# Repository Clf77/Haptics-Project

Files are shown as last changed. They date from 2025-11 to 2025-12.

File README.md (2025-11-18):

# Raspberry Pi Pico CQR37D Motor Controller

This project provides Python code to control a CQRobot CQR37D DC geared motor with quadrature encoder using a Raspberry Pi Pico microcontroller. It supports both position and velocity control through a command-line interface.

## Hardware Setup

### Required Components
- Raspberry Pi Pico
- CQRobot CQR37D DC Geared Motor with Encoder
- DROK XY-160D Motor Controller (or similar DC motor controller)
- Power supply (appropriate voltage for your motor - typically 6V, 12V, or 24V)

### Pin Connections

| Component | Pico Pin | GPIO | Wire Color (Encoder) |
|---|---|---|---|
| Encoder A | 9 | GP8 | White |
| Encoder B | 10 | GP9 | Yellow |
| Motor ENA | 1 | GP0 | Controller PWM Input |
| Motor IN1 | 2 | GP1 | Controller Direction |

### Motor Controller Setup (DROK XY-160D)
- **ENA**: Connected to Pico GP0 (pin 1) - PWM speed control
- **IN1**: Connected to Pico GP1 (pin 2) - Direction control
- **Power**: Connect appropriate DC voltage to motor controller power terminals
- **Motor**: Connect motor leads to controller output

## Software Setup

### Requirements
- MicroPython installed on Raspberry Pi Pico
- Thonny IDE (recommended) or another MicroPython editor

### Installation
1. Copy `motor_control.py` to your Raspberry Pi Pico
2. Open the file in Thonny or your preferred editor
3. Run the script

## Configuration

### Motor Parameters
Edit these values in the `MotorController.__init__()` method:

```python
self.CPR = 64  # Counts per revolution (fixed for CQR37D)
self.gear_ratio = 30.0  # Your motor's gear ratio (check your motor specs)
self.max_rpm = 150.0  # Maximum RPM for your motor/voltage combination
```

### PID Tuning (for Position Control)
Default PID values are provided, but you may need to tune them:

```python
self.kp = 2.0   # Proportional gain
self.ki = 0.1   # Integral gain
self.kd = 0.05  # Derivative gain
```

## Usage

### Command Line Interface

Run the script and use these commands:

#### Position Control
```
pos <degrees>     - Move to absolute position in degrees
Example: pos 180    (move to 180 degrees)
```

#### Velocity Control
```
vel <rpm>         - Set constant velocity in RPM
Example: vel 50     (spin at 50 RPM clockwise)
Example: vel -30    (spin at 30 RPM counter-clockwise)
```

#### Other Commands
```
stop              - Stop the motor
zero              - Zero the position counter (set current position to 0)
status            - Show current position, velocity, and control mode
pid <kp> <ki> <kd> - Set PID gains for position control
help              - Show all available commands
quit              - Exit the program
```

### Example Usage Session
```
Motor controller initialized
Encoder CPR: 64, Gear ratio: 30.0
Counts per output revolution: 1920.0

Type 'help' for available commands
Current mode: velocity control

vel 30
Velocity control: target = 30 RPM

status
Position: 45.67 degrees
Velocity: 29.85 RPM
Control mode: velocity
Target velocity: 30.00 RPM

pos 90
Position control: target = 90 degrees

status
Position: 89.94 degrees
Velocity: 0.12 RPM
Control mode: position
Target position: 90.00 degrees

stop
Motor stopped

quit
Exiting...
```

## Technical Details

### Encoder
- **Type**: Quadrature encoder with 64 counts per revolution (motor shaft)
- **Resolution**: After gearing, depends on your gear ratio
- **Interface**: Uses hardware interrupts for real-time position tracking

### Motor Control
- **Speed Control**: PWM on ENA pin (1kHz frequency)
- **Direction Control**: Digital output on IN1 pin
- **Deadband Compensation**: Minimum PWM value to overcome motor stall

### Control Modes

#### Velocity Control
- Direct RPM control
- Immediate response to velocity commands
- Good for continuous rotation applications

#### Position Control
- PID-based position control
- Maintains target angular position
- Includes integral windup protection

### Performance Considerations
- **Control Loop**: Runs at 100Hz (10ms intervals)
- **Position Accuracy**: Depends on encoder resolution and PID tuning
- **Maximum Speed**: Limited by motor capabilities and PWM frequency
- **Interrupt Latency**: MicroPython interrupt response time may affect high-speed performance

## Troubleshooting

### Common Issues

1. **Motor not moving**
   - Check power supply voltage and connections
   - Verify motor controller wiring
   - Ensure minimum PWM threshold is set correctly

2. **Inaccurate position**
   - Calibrate encoder count per revolution
   - Tune PID parameters
   - Check for mechanical backlash

3. **Velocity oscillations**
   - Reduce P gain
   - Increase D gain
   - Check encoder signal quality

4. **No encoder feedback**
   - Verify encoder pin connections
   - Check encoder power supply (3.3V-24V)
   - Ensure encoder wires are properly seated

### Calibration

1. **Encoder CPR**: Use the known value (64 for CQR37D)
2. **Gear Ratio**: Measure or check motor specifications
3. **Maximum RPM**: Test under load with your power supply
4. **PID Gains**: Start with low values and increase gradually

## Safety Notes

- **Power Supply**: Use appropriate voltage for your motor
- **Current Limiting**: Ensure your power supply can handle motor stall current
- **Mechanical Limits**: Add physical stops if needed to prevent over-rotation
- **Heat Dissipation**: Monitor motor and controller temperatures during operation

## License

This code is provided as-is for educational and experimental purposes.

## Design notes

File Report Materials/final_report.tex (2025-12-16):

\documentclass[conference]{IEEEtran}
\IEEEoverridecommandlockouts

\usepackage{cite}
\usepackage{amsmath,amssymb,amsfonts}
\usepackage{algorithmic}
\usepackage{graphicx}
\usepackage{textcomp}
\usepackage{xcolor}
\usepackage{listings}
\usepackage{tikz}
\usepackage{url}
\usepackage{float}
\usetikzlibrary{shapes,arrows,positioning}

% Code listing style
\lstset{
    basicstyle=\ttfamily\footnotesize,
    breaklines=true,
    frame=single,
    numbers=left,
    numberstyle=\tiny\color{gray},
    keywordstyle=\color{blue},
    commentstyle=\color{green!60!black},
    stringstyle=\color{red},
    showstringspaces=false
}

\def\BibTeX{{\rm B\kern-.05em{\sc i\kern-.025em b}\kern-.08em
    T\kern-.1667em\lower.7ex\hbox{E}\kern-.125emX}}

\begin{document}

\title{Haptic Lathe Simulator\\
{\large MAE 6800: Design and Control of Haptic Systems, Fall 2025}}

\author{\IEEEauthorblockN{Caleb Farrelly, Daria Kot, and Richard Zheng}
\IEEEauthorblockA{\textit{Sibley School of Mechanical and Aerospace Engineering} \\
\textit{Cornell University}\\
Ithaca, NY, USA}
}

\maketitle

\begin{abstract}
We present the design and implementation of a haptic lathe training device that simulates the tactile experience of operating a manual lathe. The system integrates a directly-driven handwheel with a virtual lathe environment, providing force feedback based on tool-material interaction, spindle speed, and cutting depth. Using a geared DC motor with a quadrature encoder as the haptic interface and a Processing-based graphical user interface, the device enables trainees to develop muscle memory for common machining operations in a low-risk setting. The haptic rendering algorithm employs a damping-based virtual wall model derived from the Hapkit framework, with material-specific force profiles for Delrin, Aluminum 6061, Stainless Steel 316, and Inconel. This paper details the system architecture, hardware implementation, control algorithms, and force rendering equations.
\end{abstract}

\begin{IEEEkeywords}
haptics, lathe simulator, force feedback, virtual machining, training systems
\end{IEEEkeywords}

\section{Introduction}

\subsection{Motivation}

Traditional lathe training relies on access to full-scale machines and close expert supervision, and it carries inherent risks including injury, tool damage, and material waste. Novice machinists must develop the tactile ``feel'' of cutting---recognizing overly aggressive feeds, dull tools, chatter onset, and material-dependent behavior at the tool--workpiece interface. Developing this intuition typically requires extensive hands-on practice.

Haptic technology offers a safer and more accessible alternative: virtual training environments that provide force feedback without the cost or hazard of physical machining. We present a two-DOF haptic lathe simulator that reproduces the hand-feel of manual lathe operation using a directly driven handwheel that can be toggled between the X cross-slide and Z carriage axes. A virtual lathe environment renders stock geometry, tool position, target drawings, and tolerances, and live X/Z readouts. The system computes and reflects cutting forces and torques as functions of spindle speed, feed, and depth of cut, enabling trainees to practice core operations such as facing and turning to diameter while building correct muscle memory in a low-risk setting.

\subsection{Educational Objectives}

The Haptic Lathe Simulator is designed to achieve the following educational objectives:

\begin{enumerate}
    \item \textbf{Muscle Memory Development}: Users develop proper hand coordination for feed control by experiencing realistic resistance during cutting operations.
    \item \textbf{Material Differentiation}: Different materials (Delrin, Aluminum, Stainless Steel, Inconel) present distinct force profiles, teaching users to recognize and adapt to material properties.
    \item \textbf{Safety Awareness}: The system simulates crash conditions when the tool contacts the workpiece with the spindle stopped and provides increased haptic resistance for overly aggressive cutting attempts, reinforcing safe operating procedures and proper feed control.
    \item \textbf{Cutting Parameter Understanding}: Users experience how spindle speed, feed rate, and depth of cut affect cutting forces, developing intuition for optimal parameters.
\end{enumerate}

\subsection{Prior Work in Haptic Machining Simulation}

A complementary user study by \cite{ieeeT4E2018} examined the perceived importance of haptic cues at the lathe handwheel across beginner, intermediate, and expert operators. Using a questionnaire-based methodology and chi-square analysis, the study found a statistically significant relationship between operator experience and perceived force intensity: beginners reported strong reliance on haptic feedback, whereas expert users perceived weaker force cues. These findings suggest that physically meaningful handwheel feedback plays a critical role during early motor-skill acquisition and motivate the inclusion of haptics in lathe training simulators.

Significant prior work has explored force-feedback interfaces for virtual machining, with an emphasis on modeling tool--workpiece interaction and material removal in real time. Early systems such as the Haptic Virtual Turning Operation System (HVTOS) employed efficient workpiece deformation algorithms to generate continuous force feedback as a function of cutting depth and material properties \cite{he2006haptic}. However, force feedback in this work was rendered using a commercial PHANToM haptic device, which, while capable of high-fidelity kinesthetic output, is expensive and does not reflect the mechanical interaction of a manual lathe, where feedback is transmitted through a rotating handwheel.

Subsequent research expanded virtual machining toward immersive visual and mixed-reality training platforms, emphasizing three-dimensional visualization, task sequencing, and safety instruction rather than physically rendered cutting forces \cite{ieee8590115, sciencedirect2016, springer2023vr}. In many of these systems, user interaction is limited to kinematic input---such as rotating a handwheel or manipulating a virtual tool---without explicit force or torque feedback. Educational implementations such as the \textit{Turnin' and Burnin'} lathe similarly focus on visual understanding of machining operations and geometry while omitting continuous, physically meaningful haptic feedback through the handwheel \cite{turninburnin}.

In contrast, the haptic lathe simulator presented in this work emphasizes the continuous, parameter-dependent hand feel of manual lathe operation. By using a directly driven handwheel and a damping-based force rendering model explicitly tied to feed rate, spindle speed, depth of cut, and material properties, our system prioritizes kinesthetic realism and muscle-memory development.

\section{System Overview}
The haptic lathe simulator consists of three primary subsystems:

\begin{enumerate}
    \item \textbf{Haptic Interface}: A CQR37D geared DC motor with integral quadrature encoder, directly coupled to a handwheel that serves as both position input and force feedback output.
    \item \textbf{Virtual Environment}: A Processing-based graphical user interface that renders the lathe workpiece, tool position, and material removal in real-time.
    \item \textbf{Control Bridge}: A Python-based communication layer that manages bidirectional data flow between the GUI and microcontroller while computing haptic forces.
\end{enumerate}

\begin{figure}[H]
    \centering
    
    \caption{Haptic Lathe Simulator Setup}
    \label{fig:placeholder}
\end{figure}
\begin{figure}[H]
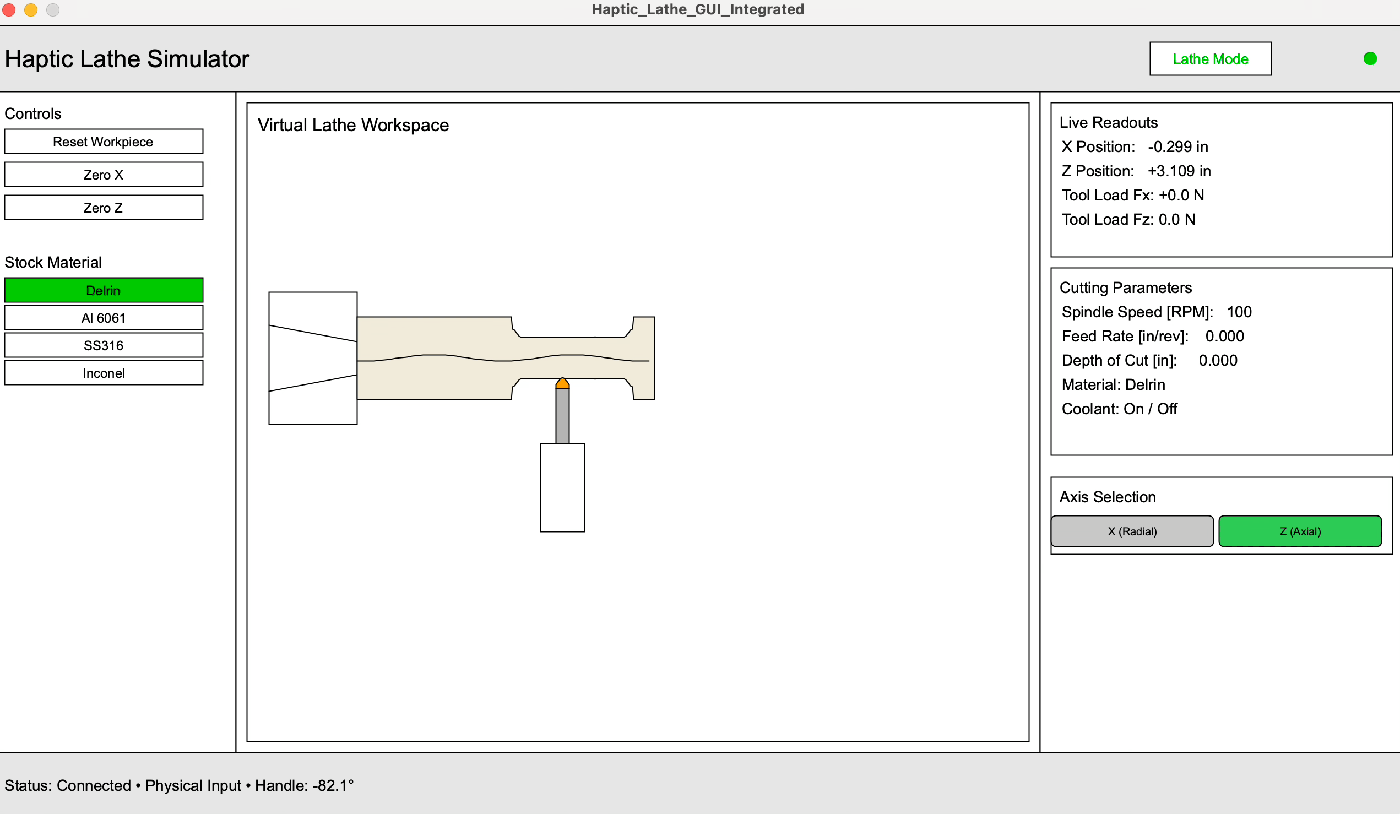
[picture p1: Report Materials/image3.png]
\centerline{}
\caption{Virtual Environment showing Delrin being cut.}
\label{fig:gui}
\end{figure}

\subsection{Project Scope}

The presented work demonstrates the principles of machining with real-time force feedback to replicate the two primary control inputs of a conventional manual lathe: the X cross-slide and the Z carriage. The resultant device is a two-DOF haptic trainer featuring one directly-driven handwheel to ensure high-fidelity transmission of simulated forces, with the operator being able to rapidly switch between the two axes. By concentrating the design on a low-inertia, directly-coupled system, the device minimizes parasitic friction and backlash, which are critical design considerations in high-precision mechanical assemblies. The system computes and reflects realistic cutting forces and torques based on operational variables, allowing trainees to practice basic machining operations (e.g., facing, turning to a specified diameter) in a safe virtual environment.

\subsection{Virtual Wall Rendering}

Virtual walls are fundamental haptic primitives that create the sensation of solid surfaces. When a user penetrates a virtual wall, the haptic device generates a restoring force proportional to penetration depth:
\begin{equation}
    F = k \cdot x
    \label{eq:spring_wall}
\end{equation}
where $k$ is the wall stiffness (N/m) and $x$ is the penetration depth (m). Pure spring walls can feel ``buzzy'' at high stiffness values, motivating the addition of damping:
\begin{equation}
    F = k \cdot x + b \cdot \dot{x}
    \label{eq:spring_damper}
\end{equation}
where $b$ is the damping coefficient (Ns/m) and $\dot{x}$ is the penetration velocity (m/s).

\subsection{Cutting Force Modeling}

In actual machining, the feed force experienced by the lathe's feed mechanism is given by:
\begin{equation}
    F_f = K_c \cdot f \cdot a_p
    \label{eq:cutting_force}
\end{equation}
where $K_c$ is the specific cutting force of the workpiece material (N/mm$^2$), $f$ is the feed per revolution (mm/rev), and $a_p$ is the depth of cut (mm). This relationship guides our haptic rendering strategy: cutting forces should increase with feed rate (velocity) and depth of cut (penetration).

\section{System Architecture}

\subsection{Architecture Overview}

The system employs a three-tier architecture with clear separation of concerns. Fig.~\ref{fig:architecture} shows the data flow between components.

% Preamble:
% \usetikzlibrary{positioning}

\begin{figure}[htbp]
\centering
\resizebox{\linewidth}{!}{%
\begin{tikzpicture}[
  node distance=1.1cm and 1.1cm,
  block/.style={
    rectangle, draw, fill=blue!20,
    text width=2.2cm, align=center,
    minimum height=1.05cm, font=\footnotesize
  },
  arrow/.style={->, thick},
  lab/.style={font=\scriptsize, fill=white, inner sep=1pt}
]

\node[block] (gui)    {Processing GUI\\(Visual)};
\node[block, right=of gui]    (bridge) {Python Bridge\\(Comm.)};
\node[block, right=of bridge] (pico)   {RPi Pico\\(Control)};
\node[block, below=of pico]   (motor)  {CQR37D\\Motor};

\draw[arrow] (gui.east)    -- node[lab, above] {TCP/IP} (bridge.west);
\draw[arrow] (bridge.east) -- node[lab, above] {Serial} (pico.west);
\draw[arrow] (pico.south)  -- (motor.north);

% Feedback path: orthogonal into faces, label offset and masked
\draw[arrow] (motor.west) -|
  node[lab, pos=0.18, above, yshift=2pt] {Position}
  (bridge.south);

\end{tikzpicture}%
}
\caption{System architecture showing data flow between components.}
\label{fig:architecture}
\end{figure}

\subsection{Communication Protocol}

The Processing GUI sends JSON-formatted commands to the Python bridge via TCP/IP on port 5005. High-speed force commands are sent at 100Hz using the format: \texttt{FORCE:<Fx>,<Fz>,<Freq>,<Yield>}.

The bridge sends text commands to the Pico microcontroller via serial at 921600 baud, including commands such as \texttt{spring\_wall}, \texttt{status}, \texttt{stop}, and \texttt{zero}.

\subsection{Update Rates}

Table~\ref{tab:timing} shows the system update rates to ensure responsive haptic feedback.

\begin{table}[htbp]
\caption{System timing parameters.}
\begin{center}
\begin{tabular}{|l|c|l|}
\hline
\textbf{Component} & \textbf{Rate} & \textbf{Purpose} \\
\hline
Pico control loop & 100 Hz & Force rendering, motor control \\
Bridge main loop & 500 Hz & Communication management \\
GUI rendering & 60 Hz & Visualization \\
Position polling & 100 Hz & Encoder/state feedback \\
Safety checks & 20 Hz & Timeouts, limits \\
\hline
\end{tabular}
\label{tab:timing}
\end{center}
\end{table}

\section{Hardware Implementation}

\subsection{Component Selection}

The haptic interface requires a motor capable of sufficient torque for realistic cutting force simulation, low friction for transparent backdrivability, and integrated encoder for position sensing.

We selected the \textbf{CQRobot CQR37D} geared DC motor. Table~\ref{tab:motor} shows its specifications. The 30:1 gear ratio provides mechanical advantage, amplifying motor torque while reducing output speed---appropriate for the slow, deliberate movements of lathe handwheel operation.

\begin{table}[htbp]
\caption{CQR37D Motor Specifications}
\begin{center}
\begin{tabular}{|l|l|}
\hline
\textbf{Parameter} & \textbf{Value} \\
\hline
Gear Ratio & 30:1 \\
Encoder CPR & 64 counts/rev (motor shaft) \\
Effective Resolution & 1920 counts/output rev \\
Rated Voltage & 12V DC \\
No-Load Speed & 150 RPM \\
Stall Torque & 3.1 Nm \\
\hline
\end{tabular}
\label{tab:motor}
\end{center}
\end{table}

The \textbf{Raspberry Pi Pico} provides dual-core ARM Cortex-M0+ at 133 MHz, hardware PWM for motor control, GPIO interrupts for encoder counting, and MicroPython support for rapid development.

\subsection{Wiring Configuration}

Table~\ref{tab:wiring} shows the hardware pin connections.

\begin{table}[htbp]
\caption{Hardware Pin Connections}
\begin{center}
\begin{tabular}{|l|l|l|l|}
\hline
\textbf{Component} & \textbf{Pico Pin} & \textbf{GPIO} & \textbf{Color} \\
\hline
Encoder A & Pin 9 & GP6 & White \\
Encoder B & Pin 10 & GP7 & Yellow \\
Motor ENA & Pin 1 & GP0 & --- \\
Motor IN1 & Pin 4 & GP2 & --- \\
Motor IN2 & Pin 2 & GP1 & --- \\
\hline
\end{tabular}
\label{tab:wiring}
\end{center}
\end{table}

\subsection{Bill of Materials}

Table~\ref{tab:bom} shows the complete bill of materials.

\begin{table}[htbp]
\caption{Bill of materials (excluding 3D-printed parts).}
\begin{center}
\begin{tabular}{|l|c|r|}
\hline
\textbf{Item} & \textbf{Qty} & \textbf{Cost} \\
\hline
Raspberry Pi Pico & 1 & \$4.00 \\
CQR37D geared DC motor (30:1) & 1 & \$34.00 \\
Motor driver (H-bridge) & 1 & \$15.70 \\
Shaft coupler & 1 & \$4.50 \\
\hline
\textbf{Total} & & \textbf{\$58.20} \\
\hline
\end{tabular}
\label{tab:bom}
\end{center}
\end{table}

\subsection{Mechanical Design}

\begin{figure}[htbp]
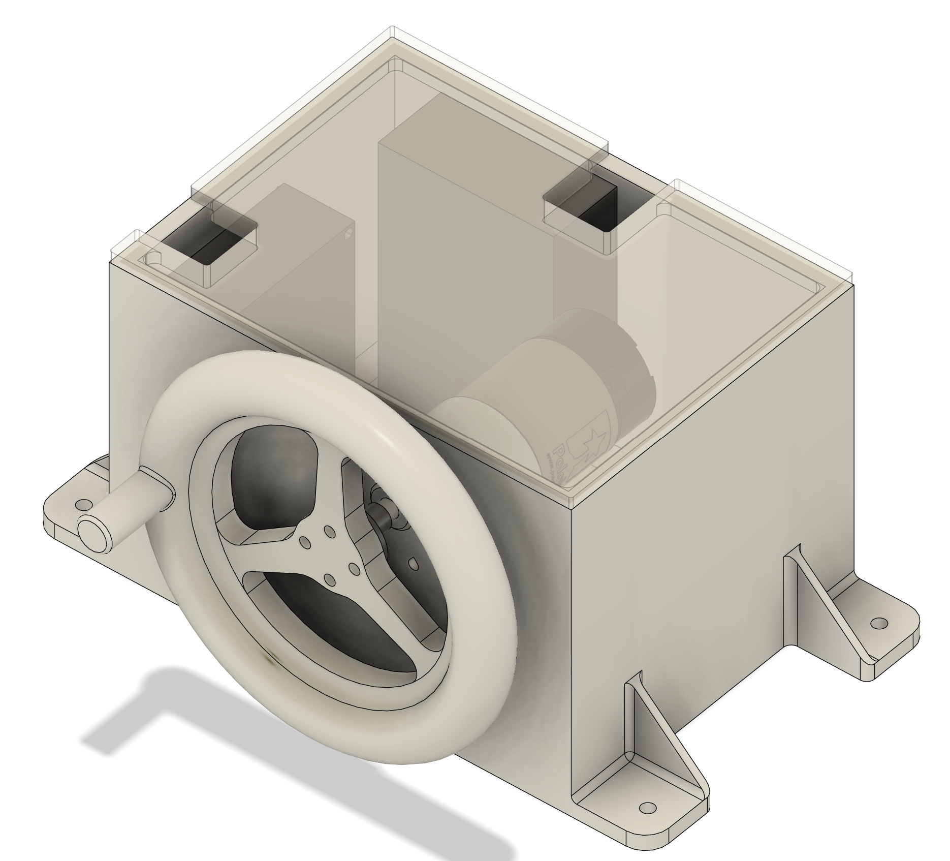
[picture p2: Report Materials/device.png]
\centerline{}
\caption{CAD of the Lathe Simulator with transparent lid.}
\label{fig:device}
\end{figure}

The mechanical assembly (Fig.~\ref{fig:device}) includes: 3D-printed housing with integrated mounting for motor and boards, 3D-printed handwheel (90mm OD) with ergonomic grip, shaft coupler connecting motor output to handwheel, and flanged base for suction cup attachment that can be clamped to the table.

\section{Software Implementation}

\subsection{Motor Control (MicroPython)}

The motor controller runs on the Raspberry Pi Pico, implementing real-time position tracking and force rendering.

\subsubsection{Quadrature Encoder Decoding}

The encoder uses hardware interrupts to track motor position. Position in degrees is computed as:
\begin{equation}
    \theta = \frac{\text{encoder\_count}}{\text{CPR} \times \text{gear\_ratio}} \times 360^\circ
    \label{eq:position}
\end{equation}

For our system: $\theta = \frac{\text{count}}{64 \times 30} \times 360^\circ = \frac{\text{count}}{1920} \times 360^\circ$.

\subsubsection{Velocity Calculation}

Angular velocity is computed by differentiating encoder counts:
\begin{equation}
    \omega = \frac{\Delta\text{count}}{\text{CPR} \times \text{gear\_ratio}} \times \frac{60}{\Delta t} \quad \text{[RPM]}
    \label{eq:velocity}
\end{equation}

An IIR low-pass filter smooths the velocity estimate:
\begin{equation}
    \dot{x}_{\text{filt}} = 0.9 \cdot \dot{x} + 0.1 \cdot \dot{x}_{\text{prev}}
    \label{eq:velocity_filter}
\end{equation}

\subsection{Virtual Wall Force Rendering}

The haptic feedback algorithm implements a damping-based cutting force model inspired by the Hapkit framework.
\subsection{Control Loop and Force Pipeline}

Fig.~\ref{fig:forcepipeline} summarizes the haptic rendering pipeline executed each control cycle. The Pico runs a fixed-rate loop at 100~Hz. Encoder counts are converted to angle $\theta$, differentiated to estimate angular velocity $\omega$, filtered, and then mapped to a handle-space linear velocity $\dot{x}_{\text{filt}} = \omega_{\text{filt}} r_h$. Penetration depth $x_{\text{pen}}$ is computed relative to the current virtual wall location. The damping-based cutting force in (8) is then converted to motor torque (9) and mapped to PWM duty (10). Finally, direction and safety logic clamp output based on penetration limits and heartbeat timeout.

\begin{figure}[htbp]
\centering
\begin{tikzpicture}[
  node distance=0.9cm,
  block/.style={rectangle, draw, fill=blue!15, text width=7.0cm, minimum height=0.75cm, align=center, font=\footnotesize},
  arrow/.style={->, thick}
]
\node[block] (enc) {Encoder counts $\rightarrow$ angle $\theta$ (Eq.~\ref{eq:position})};
\node[block, below=of enc] (vel) {Differentiate $\theta$ $\rightarrow$ $\omega$ (Eq.~\ref{eq:velocity}); low-pass filter (Eq.~\ref{eq:velocity_filter})};
\node[block, below=of vel] (handle) {Map to handle velocity: $\dot{x}_{\text{filt}}=\omega_{\text{filt}}\cdot \frac{2\pi}{60}\cdot r_h$};
\node[block, below=of handle] (pen) {Penetration depth $x_{\text{pen}}$ (Eq.~\ref{eq:penetration}) and engagement state};
\node[block, below=of pen] (force) {Compute force $F$ (Eq.~\ref{eq:damping_force}) with material scaling + yield threshold};
\node[block, below=of force] (pwm) {Torque + PWM mapping (Eq.~\ref{eq:motor_torque}, Eq.~\ref{eq:hapkit_duty}) + safety clamps};
\draw[arrow] (enc) -- (vel);
\draw[arrow] (vel) -- (handle);
\draw[arrow] (handle) -- (pen);
\draw[arrow] (pen) -- (force);
\draw[arrow] (force) -- (pwm);
\end{tikzpicture}
\caption{Force rendering pipeline executed each Pico control cycle.}
\label{fig:forcepipeline}
\end{figure}

\subsubsection{Parameterization Used in This Prototype}
The prototype used the following fixed parameters: handle radius $r_h = 0.05$~m; base damping $c_{\text{base}} = 2000$~Ns/m; depth scaling saturation $d_{\text{scale}} = \min(x_{\text{pen}}/0.005,\,2.0)$; maximum penetration of 200$^\circ$; and a 5~s heartbeat timeout. Material differences were implemented by scaling the effective damping via the yield force $F_{\text{wall}}$ (Table~\ref{tab:materials}) as $c_{\text{damping}} = c_{\text{base}} \cdot (F_{\text{wall}}/50)$, producing a 4:1 spread between Delrin and Inconel.

\subsubsection{Penetration Detection}

When the tool enters the workpiece, penetration depth is computed:
\begin{equation}
    x_{\text{pen}} = (\theta_{\text{current}} - \theta_{\text{wall}}) \cdot \text{dir} \cdot \frac{\pi}{180} \cdot r_h
    \label{eq:penetration}
\end{equation}
where $r_h = 0.05$ m is the effective handle radius.

\subsubsection{Damping-Based Force Calculation}

The cutting force is computed using velocity-proportional damping, scaled by penetration depth:
\begin{equation}
    F = -\dot{x}_{\text{filt}} \cdot c_{\text{damping}} \cdot (1 + d_{\text{scale}})
    \label{eq:damping_force}
\end{equation}
where $\dot{x}_{\text{filt}}$ is the filtered velocity at handle (m/s), $c_{\text{damping}} = c_{\text{base}} \times \frac{F_{\text{wall}}}{50}$ is the material-scaled damping with $c_{\text{base}} = 2000$ Ns/m, and $d_{\text{scale}} = \min\left(\frac{x_{\text{pen}}}{0.005}, 2.0\right)$ is the depth scaling factor.

\subsubsection{Torque-to-PWM Conversion}

The computed force is converted to motor torque and then to PWM duty cycle using the Hapkit non-linear mapping:
\begin{equation}
    T_p = \frac{F \cdot r_h}{\text{gear\_ratio}}
    \label{eq:motor_torque}
\end{equation}
\begin{equation}
    \text{duty} = \sqrt{\frac{|T_p|}{0.03}}
    \label{eq:hapkit_duty}
\end{equation}

This square-root relationship linearizes the perceived force output.

\subsection{Material Properties}

Different materials are simulated by varying the wall stiffness $k_{\text{wall}}$ and yield force. Table~\ref{tab:materials} shows the material haptic properties.

\begin{table}[htbp]
\caption{Material Haptic Properties}
\begin{center}
\begin{tabular}{|l|c|c|c|}
\hline
\textbf{Material} & \textbf{$k_{\text{wall}}$ (N/m)} & \textbf{Yield (N)} & \textbf{Color} \\
\hline
Delrin & 50,000 & 25 & Cream \\
Al 6061 & 100,000 & 50 & Silver \\
SS316 & 150,000 & 75 & Steel \\
Inconel & 200,000 & 100 & Bronze \\
\hline
\end{tabular}
\label{tab:materials}
\end{center}
\end{table}

The 4:1 ratio between softest (Delrin) and hardest (Inconel) materials provides clear tactile differentiation.

\subsection{Graphical User Interface}

The Processing-based GUI provides: (1) Virtual Lathe Workspace with real-time rendering of stock geometry, tool position, and material removal; (2) Live Readouts of X/Z position, tool load, and cutting parameters; (3) Control Panel for material selection, axis selection, and reset/zero functions; and (4) Connection Status with visual indicator for bridge connectivity.

\begin{figure}[H]
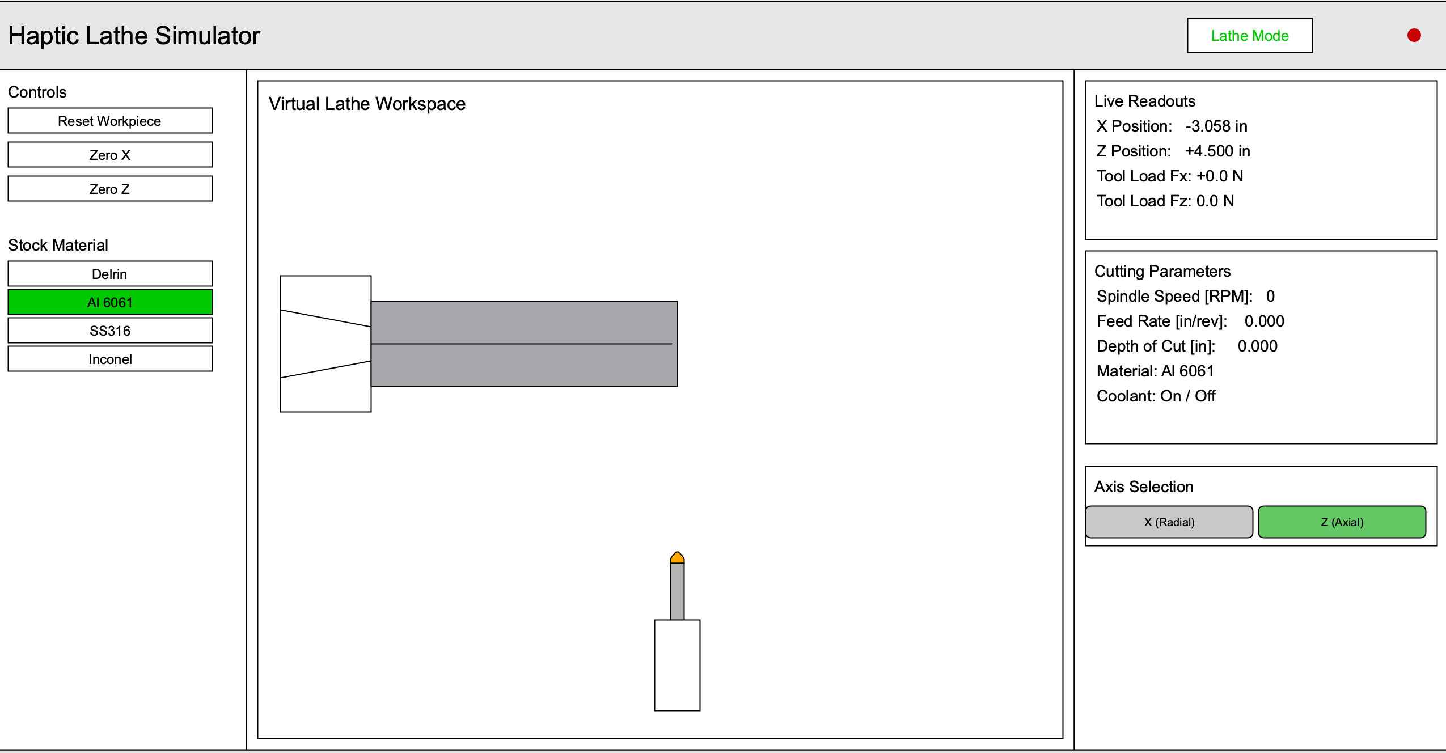
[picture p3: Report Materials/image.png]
\centerline{}
\caption{Virtual Environment showing the lathe workspace.}
\label{fig:gui}
\end{figure}

\subsubsection{Collision Detection}

The tool uses a hyperbolic profile for realistic V-tool geometry:
\begin{equation}
    y = \sqrt{(s \cdot x)^2 + R^2} - R
    \label{eq:hyperbolic_tool}
\end{equation}
where $s$ is the slope factor and $R$ is the tool tip radius. Collision is detected when the tool profile intersects the stock profile array at any Z-position.

\subsubsection{Vibration Frequency Calculation}

Cutting vibration frequency is mapped from surface feet per minute (SFM):
\begin{equation}
    \text{SFM} = \frac{\text{RPM} \times D \times \pi}{12}
    \label{eq:sfm}
\end{equation}
\begin{equation}
    f_{\text{vib}} = \text{SFM} \quad \text{[Hz]}
    \label{eq:vib_freq}
\end{equation}

This 1:1 mapping (10 SFM = 10 Hz) provides intuitive correspondence between spindle speed and haptic vibration.

\section{Results}

\subsection{Design Decisions}

Several key design decisions shaped the final system:

\begin{enumerate}
    \item \textbf{Damping-based vs. Spring-based Force Rendering}: We chose velocity-proportional damping over pure spring walls because cutting forces in actual machining are primarily determined by feed rate (velocity) rather than static position. This produces a more realistic ``cutting feel.''
    \item \textbf{Single-Axis Interface}: While a complete lathe has two axes (X and Z), we implemented a single handwheel with software axis selection. This reduces hardware complexity while maintaining training value through the axis toggle feature.
    \item \textbf{Motor as Input and Output}: Using the motor encoder as the position input (rather than a separate sensor) enables the same device to serve as both input transducer and force actuator.
\end{enumerate}

\subsection{Limitations}

\begin{enumerate}
    \item \textbf{Single Degree of Freedom}: Real lathe operation involves simultaneous X and Z control. The single-axis interface requires users to mentally switch between axes.
    \item \textbf{No Force Sensing}: The system renders forces based on virtual geometry only; actual cutting force measurement would require additional sensors.
    \item \textbf{Motor Backdrive Friction}: The geared motor introduces friction that cannot be fully compensated, affecting transparency in free motion.
\end{enumerate}

\subsection{User Study}

A formative user study was conducted during a public demonstration of the haptic lathe simulator to evaluate perceived realism, usefulness of the haptic cues, and overall learning impact. The study was exploratory (not a controlled experiment) and focused on subjective perception and qualitative feedback.

\subsubsection{Procedure}
Participants interacted freely with the simulator and were encouraged to (i) toggle between axes, (ii) try multiple materials, and (iii) vary depth of cut and feed behavior to observe changes in resistance and vibration. After the interaction, participants completed a short questionnaire with 10-point Likert items (1 = strongly disagree, 10 = strongly agree) and optional open-ended comments. Participants also answered whether they felt more confident operating a lathe afterward (Yes/No).

\subsubsection{Participants}
Ten participants completed the questionnaire ($N=10$). Seven reported prior lathe experience, two reported no prior lathe experience, and one left the question blank. This mix allowed feedback from both experienced users (realism expectations) and novices (interpretability of cues).

\subsubsection{Measures}
Participants rated the following statements: (1) The simulation was realistic; (2) The materials were differentiable; (3) Force changes communicate tool engagement; (4) I could tell when I was doing something ``wrong'' based on feel alone; (5) The visual and haptic cues were synchronized; (6) The simulator helped me understand lathe cutting dynamics. Participants also reported whether they felt more confident operating a lathe after use.

\subsubsection{Results}
Table~\ref{tab:userstudy} summarizes the Likert responses. Overall scores were high across all dimensions, with particularly strong ratings for visual--haptic synchronization and understanding of cutting dynamics. All participants reported increased confidence operating a lathe after using the simulator (10/10 ``Yes'').

\begin{table}[htbp]
\caption{User study Likert responses (1--10).}
\begin{center}
\begin{tabular}{lccc}
\hline
\textbf{Statement} & \textbf{Mean} & \textbf{SD} & \textbf{Range} \\
\hline
Simulation was realistic & 8.9 & 0.9 & 8--10 \\
Materials differentiable & 9.0 & 1.1 & 7--10 \\
Force indicates engagement & 9.0 & 1.6 & 6--10 \\
Could detect ``wrong'' by feel & 8.4 & 1.6 & 5--10 \\
Visual--haptic synchronized & 9.9 & 0.3 & 9--10 \\
Helped understand cutting dynamics & 9.8 & 0.6 & 8--10 \\
\hline
\end{tabular}
\label{tab:userstudy}
\end{center}
\end{table}

\begin{table}[htbp]
\caption{User study means by experience group (Likert 1--10).}
\begin{center}
\begin{tabular}{lcc}
\hline
\textbf{Statement} & \textbf{Experienced (n=7)} & \textbf{Novice (n=2)} \\
\hline
Simulation was realistic & 8.6 & 9.5 \\
Materials differentiable & 9.1 & 9.0 \\
Force indicates engagement & 9.1 & 10.0 \\
Could detect ``wrong'' by feel & 8.1 & 8.5 \\
Visual--haptic synchronized & 9.9 & 9.5 \\
Helped understand cutting dynamics & 9.7 & 10.0 \\
\hline
\end{tabular}
\label{tab:userstudy_groups}
\end{center}
\end{table}

\noindent
Novice users tended to rate tool engagement and learning impact slightly higher, while experienced users provided more critical realism scores, consistent with expert calibration to real machine feel. Although the novice sample is small, this split suggests the simulator is interpretable for first-time learners while remaining recognizable to users with prior lathe exposure.

\subsubsection{Qualitative Feedback}
Open-ended comments highlighted (i) perceived realism of resistance changes with depth of cut (including experienced-user agreement that it ``matched the feel''), and (ii) the usefulness of haptic cues for identifying aggressive cutting without relying on visuals. One participant noted that the suction-cup mounting reduced immersion, suggesting improved fixturing (e.g., clamps or a heavier base) for future iterations.

\subsubsection{Study Limitations}
This evaluation was conducted in an uncontrolled demo setting with a small sample size, so results should be interpreted as formative. Participants had different exposure times and explored different subsets of operations. A controlled follow-on study could standardize tasks (e.g., facing to a target diameter under fixed spindle speed), compare conditions (haptics on/off), and measure objective performance (time-to-completion, overshoot, surface error, and number of ``crash'' events).

\subsection{Discussion}

The results suggest that the simulator successfully conveys key aspects of manual lathe operation through haptic feedback, particularly in communicating tool engagement, material differences, and unsafe cutting conditions. The consistently high ratings for visual--haptic synchronization indicate that the tight coupling between force rendering and graphical feedback contributed to a coherent user experience.

Importantly, both experienced and novice users reported benefits, supporting the hypothesis that physically meaningful handwheel feedback can aid early skill acquisition while remaining recognizable to expert operators. While the small sample size limits statistical generalization, these findings align with prior work emphasizing the role of haptics in motor-skill learning and motivate further controlled studies with larger participant groups.

\section{Future Work}

\begin{enumerate}
    \item \textbf{Two-Axis Implementation}: Add a second motor/handwheel for simultaneous X and Z control.
    \item \textbf{Force Sensing}: Integrate torque sensors for closed-loop force control.
    \item \textbf{Milling Mode}: The architecture extends naturally to milling simulation as a stretch goal.
    \item \textbf{Extended User Study}: Conduct a formal study comparing training outcomes between haptic and non-haptic simulation.
    \item \textbf{Audio Feedback}: Add cutting sounds synchronized with spindle speed and material for multi-modal feedback.
\end{enumerate}

\section{Conclusion}

We have presented the design, implementation, and initial evaluation of a haptic lathe training simulator. The system successfully renders material-dependent cutting forces through a directly-driven handwheel interface, enabling users to experience realistic resistance during virtual machining operations.

Key contributions include: (1) A three-tier architecture separating visualization, communication, and real-time control; (2) A damping-based force rendering algorithm that produces realistic cutting feel; (3) Material differentiation through adjustable wall stiffness and yield force parameters; (4) Safety features including crash detection and emergency stop functionality.

The system demonstrates that effective haptic machining training can be achieved with modest hardware (total cost under \$60) while providing meaningful tactile feedback for skill development.

\section*{Acknowledgments}

AI systems used: Claude Opus 4.5 was used to convert existing codebase documentation and project notes into a well formatted LaTeX final report. The prompt instructed the system to read the repository and the provided background document, produce detailed implementation sections describing the software and hardware (including equations and concept explanations), and insert explicit placeholders wherever required information was missing rather than inventing results. This use primarily improved report structure, formatting quality, and clarity of code and hardware descriptions, while keeping technical content constrained to what was already present in the codebase and project files.

Google Gemini was also selectively used to fix grammatical errors in this report and smooth out sentence structures. The AI was prompted ``proof read, dont change tone and content, make list of changes and I will implement them''.

\begin{thebibliography}{00}

\bibitem{he2006haptic}
X. He and Y. Chen, ``A Haptic Virtual Turning Operation System,'' in \textit{Proc. IEEE Int. Conf. on Mechatronics and Automation}, Luoyang, China, 2006, pp. 435--440.

\bibitem{ieee8590115}
S. B. Choudhury, S. K. Saha, and A. K. Mukherjee, ``A Virtual Machining Simulator for Training and Education,'' \textit{IEEE Trans. Learning Technologies}, vol. 12, no. 3, pp. 386--398, 2019.

\bibitem{sciencedirect2016}
S. Mishra, S. K. Saha, and A. K. Mukherjee, ``Development of a virtual machining environment with haptic feedback,'' \textit{Procedia Manufacturing}, vol. 5, pp. 538--549, 2016.

\bibitem{springer2023vr}
A. D. Silva, J. Pereira, and M. A. Otaduy, ``A virtual reality lathe simulator with visuo-haptic feedback for machining training,'' \textit{Virtual Reality}, vol. 27, no. 2, pp. 1121--1136, 2023.

\bibitem{ieee5406525}
C. Basdogan, S. De, J. Kim, M. Muniyandi, H. Kim, and M. A. Srinivasan, ``Haptics in minimally invasive surgical simulation and training,'' \textit{IEEE Computer Graphics and Applications}, vol. 24, no. 2, pp. 56--64, 2004.

\bibitem{ieee4026122}
K. Salisbury, F. Conti, and F. Barbagli, ``Haptic rendering: introductory concepts,'' \textit{IEEE Computer Graphics and Applications}, vol. 24, no. 2, pp. 24--32, 2004.

\bibitem{ieeeT4E2018}
A. Akshay, R. Raghavan, and S. K. Saha, ``Significance of Haptic Feedback in Learning Lathe Operating Skills,'' in \textit{Proc. IEEE Tenth Int. Conf. on Technology for Education (T4E)}, Chennai, India, 2018, pp. 112--119.

\bibitem{hapkit}
J. K. Salisbury, K. J. Kuchenbecker, and the Stanford Haptics Group, ``The Hapkit: A low-cost haptic device for education and research,'' Stanford University. [Online]. Available: https://hapkit.stanford.edu

\bibitem{turninburnin}
Turnin' and Burnin' Haptic Lathe Project, Lafayette College. [Online]. Available: https://sites.lafayette.edu/turnin-and-burnin/

\end{thebibliography}

\section*{Appendix: File Descriptions}

The following files are included for reproduction of this project:

\begin{enumerate}
    \item \texttt{run\_integrated\_system.py}: Main launcher script. \textbf{To start the system}, run \texttt{python run\_integrated\_system.py} from the project root. This starts the Python bridge and opens the Processing GUI.
    
    \item \texttt{integrated\_lathe\_controller.py}: Python bridge that manages TCP communication between the GUI and the Raspberry Pi Pico microcontroller. Computes haptic forces and relays commands.
    
    \item \texttt{pico\_upload/main.py}: Pico boot script that initializes the motor controller and listens for serial commands. \textbf{Upload this file to the Pico} along with \texttt{motor\_control.py}.
    
    \item \texttt{pico\_upload/motor\_control.py}: MicroPython firmware implementing quadrature encoder reading, PID position/velocity control, and damping-based virtual wall haptic rendering.
    
    \item \texttt{Haptic\_Lathe\_GUI/Haptic\_Lathe\_GUI\_Integrated.pde}: Processing sketch for the virtual lathe GUI. Renders stock geometry, tool position, and material removal in real-time; sends force commands to the Python bridge via TCP.
    
    \item \texttt{lathe\_config.ini}: Configuration file specifying serial port names and system parameters.
    
    \item \texttt{INTEGRATED\_SYSTEM\_README.md}: Comprehensive setup and usage guide for the integrated system.
    
    \item \texttt{UPLOAD\_INSTRUCTIONS.md}: Step-by-step instructions for uploading firmware to the Raspberry Pi Pico using Thonny or \texttt{mpremote}.
    
    \item \texttt{New+Assembly.f3z}: Fusion 360 CAD assembly file containing the complete mechanical design.
    
    \item \texttt{Report Materials/device.png}: CAD rendering of the haptic lathe device assembly.
\end{enumerate}

\end{document}

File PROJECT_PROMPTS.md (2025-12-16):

# Project Prompts: Haptic Lathe

This document contains a compilation of user prompts and objectives from the current and previous sessions relevant to the Haptic Lathe project.

## Current Session: Refining Material Stiffness & Code Cleanup
**Date:** Dec 13, 2025

1.  **Objective:** Refining Material Stiffness
    *   *Context:* Adjusting material properties for the virtual lathe simulation (`k_wall`, Yield Force) and adding 'Inconel'.
2.  "Comment out all the printing commands."
3.  "How is the vibration amplitude being calculated? Is it actually being rendered?"
4.  "WHy is the free spinning gone? bring back the motor control from d8097d7b6e8c95639239d7db0af67803ca7056b3"
5.  "Make the up and down arrow keys control the spindle speed"
6.  "Change inconel stiffness to 2x 6061 then push to github"
7.  "Why does it cut through the middle suddnely whithout actually reachign the midpoitn when cutting radially"
8.  "Push to github"
9.  "Remove AI code slop"
    *   *Details:* "remove all AI generated slop introduced in this codebase. This includes: Extra comments... Extra defensive checks... Casts to any... Inconsistent style... Orphaned functions..."
10. "Clean up the gui file too"
11. "Push to github"
12. "Make the code we just commited the main branch"
13. "Put all prompts used in this project into a markdown file across all relevant chats"

## Previous Session: Refine Lathe Haptics and Controls
**Date:** Dec 04, 2025

1.  **Objective:** Refine Lathe Haptics and Controls
    *   *Goals:*
        *   Implement "Crash" behavior (0 RPM contact).
        *   Reverse control direction for Z-axis (axial) and X-axis (radial).
        *   Update force reaction direction to match new controls.

## Session: Damping Feedback Experiments
**Date:** Dec 03, 2025

1.  "Implement Damping Haptic Feedback"
    *   *Context:* Replacing virtual wall with velocity-based damping.
2.  "There was NO force rendered at all" / "Fundamental issue with pico communication"
3.  "Revert to the last main commit"
4.  "remove all haptic feedback from current code, implement damping as feedback... Damping force should be around 50n maximum. Make a plan and wait for my approval"
5.  "change the current spring constant to 0.2x the current value"
6.  "Add the prompts from this chat to the project prompts file"

## Previous Session: Fixing Haptic Feedback
**Date:** Dec 02, 2025

1.  **Objective:** Fixing Haptic Feedback
    *   *Goals:*
        *   Fix axial haptic feedback (prevent "reset to start" bug).
        *   Ensure correct behavior for "Reset Workpiece" button.
        *   Diagnose and resolve axial feedback issues.

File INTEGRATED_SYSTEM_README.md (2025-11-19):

# Integrated Haptic Lathe System

This project integrates a Processing-based GUI simulator with a physical motor controller to create a complete haptic lathe training system. The handle wheel on the motor becomes the primary input device for tool positioning.

## System Architecture

```
┌─────────────────┐    Serial     ┌──────────────────┐    Serial     ┌─────────────────┐
│   Processing    │ ────────────► │   Python Bridge  │ ◄───────────► │   Raspberry Pi  │
│      GUI        │               │   Controller     │               │      Pico       │
│                 │ ◄──────────── │                  │ ─────────────► │   Motor Control │
└─────────────────┘               └──────────────────┘               └─────────────────┘
         ▲                              ▲                                      │
         │                              │                                      ▼
         └──────────────────────────────┘                            ┌─────────────────┐
                                                         Handle      │    CQR37D       │
                                                         Wheel       │   Geared Motor  │
                                                         Position     │   + Encoder     │
                                                                      └─────────────────┘
```

## Features

- **Physical Handle Wheel Input**: Motor encoder provides real-time position feedback
- **Haptic Feedback**: Motor can provide force feedback (future enhancement)
- **Training Modes**: Facing, Turning, and Boring operations
- **Skill Levels**: Beginner, Intermediate, Advanced with different assistance levels
- **Safety Features**: Emergency stop, position limits, heartbeat monitoring
- **Dual Input Modes**: Toggle between physical handle wheel and mouse control

## Hardware Requirements

### Required Components
- Raspberry Pi Pico (or compatible microcontroller)
- CQR37D DC Geared Motor with Encoder
- DC Motor Controller (DROK XY-160D or similar)
- Handle wheel attached to motor shaft
- Power supply appropriate for motor (6V-24V DC)
- Computer with Processing IDE installed

### Pin Connections

| Component | Pico Pin | GPIO | Wire Color |
|---|---|---|---|
| Encoder A | 9 | GP8 | White |
| Encoder B | 10 | GP9 | Yellow |
| Motor ENA | 1 | GP0 | PWM Speed |
| Motor IN1 | 2 | GP1 | Direction |

## Software Setup

### Quick Setup
```bash
# Run setup script
python setup_integrated_system.py

# Run the integrated system
python run_integrated_system.py
```

### Manual Setup

1. **Install Dependencies**
   ```bash
   pip install pyserial
   ```

2. **Install Processing IDE**
   - Download from: https://processing.org/
   - macOS: Install to /Applications/
   - Linux/Windows: Install to system path

3. **Upload Motor Control to Pico**
   ```bash
   # Use Thonny or your preferred MicroPython editor
   # Upload motor_control.py to your Pico
   ```

## Configuration

Edit `lathe_config.ini` to customize settings:

```ini
[serial_ports]
gui_port = /dev/ttyACM0    # Auto-detected if empty
pico_port = /dev/ttyACM1   # Auto-detected if empty

[motor_config]
encoder_cpr = 64           # Encoder counts per revolution
gear_ratio = 30.0          # Your motor's gear ratio
max_rpm = 150.0           # Maximum motor RPM

[safety_limits]
max_velocity = 100.0      # Safety velocity limit
max_position_error = 10.0 # Position error threshold
heartbeat_timeout = 5.0   # Connection timeout
```

## Usage

### Starting the System

```bash
python run_integrated_system.py
```

This will:
1. Start the Python bridge controller
2. Launch the Processing GUI
3. Establish serial communication between components

### GUI Controls

- **Training Scenario Buttons**: Select Facing, Turning, or Boring operations
- **Skill Level**: Choose Beginner, Intermediate, or Advanced
- **Control Buttons**:
  - Reset: Reset workpiece and zero positions
  - Zero X/Z: Zero position readouts
  - Show Toolpath: Toggle cutting path visualization

### Keyboard Shortcuts

- **Spacebar**: Emergency stop (sends stop command to motor)
- **P**: Toggle between physical handle wheel and mouse input
- **Ctrl+C**: Shutdown entire system

### Physical Operation

1. **Power on** motor controller and ensure proper voltage
2. **Start system** using the launcher script
3. **Select training mode** in the GUI
4. **Turn handle wheel** to position the cutting tool
5. **Monitor position** in real-time on the GUI display

## Communication Protocol

### GUI → Bridge (JSON)
```json
{"type": "mode_change", "mode": "facing", "skill_level": "beginner"}
{"type": "set_parameters", "spindle_rpm": 500, "feed_rate": 0.005}
{"type": "emergency_stop"}
{"type": "zero_position", "axis": "x"}
{"type": "reset"}
```

### Bridge → GUI (JSON)
```json
{
  "type": "status_update",
  "handle_wheel_position": 45.67,
  "mode": "facing",
  "skill_level": "beginner",
  "emergency_stop": false,
  "spindle_rpm": 500,
  "feed_rate": 0.005,
  "timestamp": 1640995200.0
}
```

### Bridge ↔ Pico (Text Commands)
```
pos 180          # Move to 180 degrees
vel 50           # Set velocity to 50 RPM
stop             # Stop motor
status           # Get current status
zero             # Zero position
```

## Safety Features

- **Emergency Stop**: Spacebar or GUI button immediately stops motor
- **Position Limits**: Software limits prevent over-rotation
- **Heartbeat Monitoring**: Detects communication loss
- **Velocity Limiting**: Maximum RPM enforced in software
- **Error Detection**: Position error monitoring with automatic shutdown

## Troubleshooting

### Common Issues

1. **"No serial port found"**
   - Check USB connections
   - Try different USB ports
   - Ensure Pico is properly flashed with MicroPython

2. **Motor not responding**
   - Verify power supply voltage
   - Check motor controller wiring
   - Confirm PWM pin connections

3. **GUI won't start**
   - Ensure Processing IDE is installed
   - Check sketch file path
   - Try running Processing manually

4. **Position inaccurate**
   - Calibrate encoder CPR and gear ratio
   - Check for mechanical backlash
   - Verify encoder signal quality

### Debug Mode

Run individual components for testing:

```bash
# Test motor controller only
python motor_control.py

# Test bridge only (no Pico connected)
python integrated_lathe_controller.py

# Test GUI only (no bridge connected)
# Open Haptic_Lathe_GUI_Integrated.pde in Processing IDE
```

## Development

### Adding New Features

1. **New GUI Controls**: Add to `Haptic_Lathe_GUI_Integrated.pde`
2. **Motor Commands**: Extend `integrated_lathe_controller.py`
3. **Safety Features**: Add to safety monitoring in bridge controller

### Code Structure

- `integrated_lathe_controller.py`: Python bridge between GUI and motor
- `Haptic_Lathe_GUI_Integrated.pde`: Processing GUI with serial communication
- `run_integrated_system.py`: System launcher and process manager
- `setup_integrated_system.py`: Dependency installer and configurator

## Future Enhancements

- **Haptic Feedback**: Motor resistance based on cutting forces
- **Force Sensing**: Measure actual cutting forces
- **Advanced Training**: Path following and skill assessment
- **Multi-axis Control**: Add X and Z axis motors
- **Network Operation**: Web-based interface for remote training

## License

This project is provided for educational and experimental purposes.

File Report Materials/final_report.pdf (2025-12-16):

# Haptic Lathe Simulator

MAE 6800: Design and Control of Haptic Systems, Fall 2025

Caleb Farrelly, Daria Kot, and Richard Zheng
Sibley School of Mechanical and Aerospace Engineering Cornell University
Ithaca, NY, USA

Abstract—We present the design and implementation of a haptic lathe training device that simulates the tactile experience of operating a manual lathe. The system integrates a directly-driven handwheel with a virtual lathe environment, providing force feedback based on tool-material interaction, spindle speed, and cutting depth. Using a geared DC motor with a quadrature encoder as the haptic interface and a Processing-based graphical user interface, the device enables trainees to develop muscle memory for common machining operations in a low-risk setting. The haptic rendering algorithm employs a damping-based virtual wall model derived from the Hapkit framework, with materialspecific force profiles for Delrin, Aluminum 6061, Stainless Steel 316, and Inconel. This paper details the system architecture, hardware implementation, control algorithms, and force rendering equations.
Index Terms—haptics, lathe simulator, force feedback, virtual machining, training systems
I. INTRODUCTION
A. Motivation

Traditional lathe training relies on access to full-scale machines and close expert supervision, and it carries inherent risks including injury, tool damage, and material waste. Novice machinists must develop the tactile “feel” of cutting— recognizing overly aggressive feeds, dull tools, chatter onset, and material-dependent behavior at the tool–workpiece interface. Developing this intuition typically requires extensive hands-on practice.
Haptic technology offers a safer and more accessible alternative: virtual training environments that provide force feedback without the cost or hazard of physical machining. We present a two-DOF haptic lathe simulator that reproduces the hand-feel of manual lathe operation using a directly driven handwheel that can be toggled between the X cross-slide and Z carriage axes. A virtual lathe environment renders stock geometry, tool position, target drawings, and tolerances, and live X/Z readouts. The system computes and reflects cutting forces and torques as functions of spindle speed, feed, and depth of cut, enabling trainees to practice core operations such as facing and turning to diameter while building correct muscle memory in a low-risk setting.
B. Educational Objectives

The Haptic Lathe Simulator is designed to achieve the following educational objectives:

1) Muscle Memory Development: Users develop proper hand coordination for feed control by experiencing realistic resistance during cutting operations.
2) Material Differentiation: Different materials (Delrin, Aluminum, Stainless Steel, Inconel) present distinct force profiles, teaching users to recognize and adapt to material properties.
3) Safety Awareness: The system simulates crash conditions when the tool contacts the workpiece with the spindle stopped and provides increased haptic resistance for overly aggressive cutting attempts, reinforcing safe operating procedures and proper feed control.
4) Cutting Parameter Understanding: Users experience how spindle speed, feed rate, and depth of cut affect cutting forces, developing intuition for optimal parameters.
C. Prior Work in Haptic Machining Simulation
A complementary user study by [?] examined the perceived importance of haptic cues at the lathe handwheel across beginner, intermediate, and expert operators. Using a questionnaire-based methodology and chi-square analysis, the study found a statistically significant relationship between operator experience and perceived force intensity: beginners reported strong reliance on haptic feedback, whereas expert users perceived weaker force cues. These findings suggest that physically meaningful handwheel feedback plays a critical role during early motor-skill acquisition and motivate the inclusion of haptics in lathe training simulators.
Significant prior work has explored force-feedback interfaces for virtual machining, with an emphasis on modeling tool–workpiece interaction and material removal in real time. Early systems such as the Haptic Virtual Turning Operation System (HVTOS) employed efficient workpiece deformation algorithms to generate continuous force feedback as a function of cutting depth and material properties [?]. However, force feedback in this work was rendered using a commercial PHANToM haptic device, which, while capable of highfidelity kinesthetic output, is expensive and does not reflect the mechanical interaction of a manual lathe, where feedback is transmitted through a rotating handwheel.
Subsequent research expanded virtual machining toward immersive visual and mixed-reality training platforms, emphasizing three-dimensional visualization, task sequencing, and safety instruction rather than physically rendered cutting forces

[?], [?], [?]. In many of these systems, user interaction is limited to kinematic input—such as rotating a handwheel or manipulating a virtual tool—without explicit force or torque feedback. Educational implementations such as the Turnin’ and Burnin’ lathe similarly focus on visual understanding of machining operations and geometry while omitting continuous, physically meaningful haptic feedback through the handwheel [?].
In contrast, the haptic lathe simulator presented in this work emphasizes the continuous, parameter-dependent hand feel of manual lathe operation. By using a directly driven handwheel and a damping-based force rendering model explicitly tied to feed rate, spindle speed, depth of cut, and material properties, our system prioritizes kinesthetic realism and muscle-memory development.

II. SYSTEM OVERVIEW

The haptic lathe simulator consists of three primary subsystems:

1) Haptic Interface: A CQR37D geared DC motor with integral quadrature encoder, directly coupled to a handwheel that serves as both position input and force feedback output.
2) Virtual Environment: A Processing-based graphical user interface that renders the lathe workpiece, tool position, and material removal in real-time.
3) Control Bridge: A Python-based communication layer that manages bidirectional data flow between the GUI and microcontroller while computing haptic forces.

image2.png

Fig. 1. Haptic Lathe Simulator Setup

image3.png

Fig. 2. Virtual Environment showing Delrin being cut.

A. Project Scope

The presented work demonstrates the principles of machining with real-time force feedback to replicate the two primary control inputs of a conventional manual lathe: the X cross-slide and the Z carriage. The resultant device is a two-DOF haptic trainer featuring one directly-driven handwheel to ensure highfidelity transmission of simulated forces, with the operator being able to rapidly switch between the two axes. By concentrating the design on a low-inertia, directly-coupled system, the device minimizes parasitic friction and backlash, which are critical design considerations in high-precision mechanical assemblies. The system computes and reflects realistic cutting forces and torques based on operational variables, allowing trainees to practice basic machining operations (e.g., facing, turning to a specified diameter) in a safe virtual environment.

B. Virtual Wall Rendering

Virtual walls are fundamental haptic primitives that create the sensation of solid surfaces. When a user penetrates a virtual wall, the haptic device generates a restoring force proportional to penetration depth:
F = k · x | (1)

where k is the wall stiffness (N/m) and x is the penetration depth (m). Pure spring walls can feel “buzzy” at high stiffness values, motivating the addition of damping:

F = k · x + b · x˙ | (2)

where b is the damping coefficient (Ns/m) and x˙ is the penetration velocity (m/s).

C. Cutting Force Modeling

In actual machining, the feed force experienced by the lathe’s feed mechanism is given by:

Ff = Kc · f · ap | (3)

where Kc is the specific cutting force of the workpiece material (N/mm²
), f is the feed per revolution (mm/rev), and ap is the depth of cut (mm). This relationship guides our haptic rendering strategy: cutting forces should increase with feed rate (velocity) and depth of cut (penetration).

III. SYSTEM ARCHITECTURE

A. Architecture Overview

The system employs a three-tier architecture with clear separation of concerns. Fig. ?? shows the data flow between components.

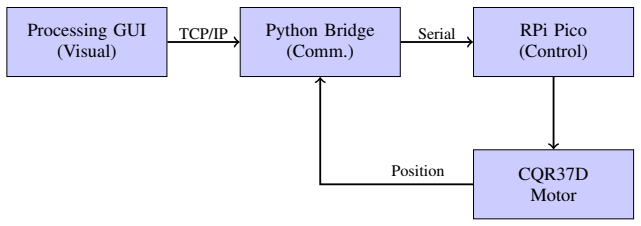
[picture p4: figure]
Processing GUI (Visual); Python Bridge (Comm.); RPi Pico (Control); CQR37D Motor; TCP/IP; Serial; Position

Fig. 3. System architecture showing data flow between components.

B. Communication Protocol

The Processing GUI sends JSON-formatted commands to the Python bridge via TCP/IP on port 5005. Highspeed force commands are sent at 100Hz using the format:
FORCE:<Fx>,<Fz>,<Freq>,<Yield>.
The bridge sends text commands to the Pico microcontroller via serial at 921600 baud, including commands such as
spring_wall, status, stop, and zero.
C. Update Rates

Table ?? shows the system update rates to ensure responsive haptic feedback.

TABLE I
SYSTEM TIMING PARAMETERS.
Component | Rate | Purpose
Pico control loop Bridge main loop GUI rendering Position polling Safety checks | 100 Hz 500 Hz 60 Hz 100 Hz 20 Hz | Force rendering, motor control Communication management Visualization Encoder/state feedback Timeouts, limits

IV. HARDWARE IMPLEMENTATION

A. Component Selection
The haptic interface requires a motor capable of sufficient torque for realistic cutting force simulation, low friction for transparent backdrivability, and integrated encoder for position sensing.
We selected the CQRobot CQR37D geared DC motor. Table ?? shows its specifications. The 30:1 gear ratio provides mechanical advantage, amplifying motor torque while reducing output speed—appropriate for the slow, deliberate movements of lathe handwheel operation.

TABLE II
CQR37D MOTOR SPECIFICATIONS
Parameter | Value
Gear Ratio Encoder CPR Effective Resolution Rated Voltage No-Load Speed Stall Torque | 30:1 64 counts/rev (motor shaft) 1920 counts/output rev 12V DC 150 RPM 3.1 Nm

The Raspberry Pi Pico provides dual-core ARM Cortex-M0+ at 133 MHz, hardware PWM for motor control, GPIO interrupts for encoder counting, and MicroPython support for rapid development.

B. Wiring Configuration
Table ?? shows the hardware pin connections.

TABLE III
HARDWARE PIN CONNECTIONS
Component | Pico Pin | GPIO | Color
Encoder A Encoder B Motor ENA Motor IN1 Motor IN2 | Pin 9 Pin 10 Pin 1 Pin 4 Pin 2 | GP6 GP7 GP0 GP2 GP1 | White Yellow — — —
C. Bill of Materials
Table ?? shows the complete bill of materials.

TABLE IV
BILL OF MATERIALS (EXCLUDING 3D-PRINTED PARTS).
Item | Qty | Cost
Raspberry Pi Pico CQR37D geared DC motor (30:1) Motor driver (H-bridge) Shaft coupler | 1 1 1 1 | $4.00 $34.00 $15.70 $4.50
Total | | $58.20
D. Mechanical Design
The mechanical assembly (Fig. ??) includes: 3D-printed housing with integrated mounting for motor and boards, 3D-printed handwheel (90mm OD) with ergonomic grip, shaft coupler connecting motor output to handwheel, and flanged


Fig. 4. CAD of the Lathe Simulator with transparent lid.

base for suction cup attachment that can be clamped to the table.

V. SOFTWARE IMPLEMENTATION
A. Motor Control (MicroPython)
The motor controller runs on the Raspberry Pi Pico, implementing real-time position tracking and force rendering.
1) Quadrature Encoder Decoding: The encoder uses hardware interrupts to track motor position. Position in degrees is computed as:

θ =

encoder count
CPR × gear ratio

× 360◦
(4)

For our system: θ =

count

64×30 × 360◦ =
count

1920 × 360◦
2) Velocity Calculation: Angular velocity is computed by differentiating encoder counts:

ω =

∆count
CPR × gear ratio

×

60
∆t
[RPM] | (5)

An IIR low-pass filter smooths the velocity estimate:

x˙ filt = 0.9 · x˙ + 0.1 · x˙ prev | (6)
B. Virtual Wall Force Rendering
The haptic feedback algorithm implements a damping-based cutting force model inspired by the Hapkit framework.
C. Control Loop and Force Pipeline
Fig. ?? summarizes the haptic rendering pipeline executed each control cycle. The Pico runs a fixed-rate loop at 100 Hz. Encoder counts are converted to angle θ, differentiated to estimate angular velocity ω, filtered, and then mapped to a handle-space linear velocity x˙ filt = ωfiltrh. Penetration depth xpen is computed relative to the current virtual wall location. The damping-based cutting force in (8) is then converted to motor torque (9) and mapped to PWM duty (10). Finally, direction and safety logic clamp output based on penetration limits and heartbeat timeout.

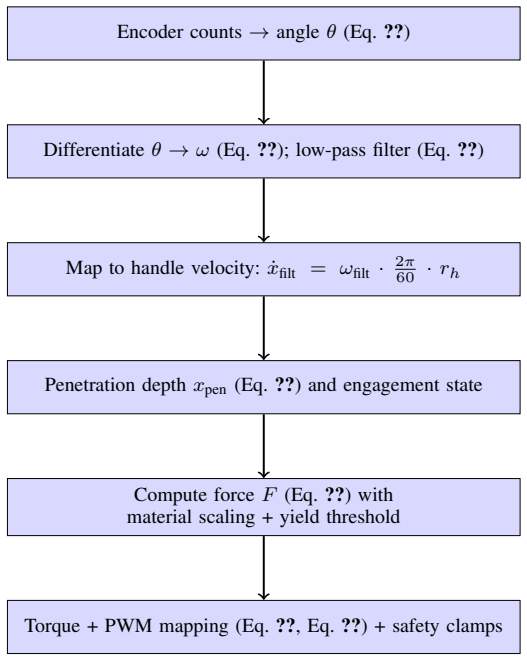
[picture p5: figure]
Encoder counts → angle θ (Eq. ??); Compute force F (Eq. ??) with material scaling + yield threshold

Differentiate θ → ω (Eq. ??); low-pass filter (Eq. ??)

Map to handle velocity: x˙ filt = ωfilt ·

Penetration depth xpen (Eq. ??) and engagement state

Torque + PWM mapping (Eq. ??, Eq. ??) + safety clamps

Fig. 5. Force rendering pipeline executed each Pico control cycle.

1) Parameterization Used in This Prototype: The prototype used the following fixed parameters: handle radius rh = 0.05 m; base damping cbase = 2000 Ns/m; depth scaling saturation dscale = min(xpen/0.005, 2.0); maximum penetration of 200◦
; and a 5 s heartbeat timeout. Material differences were implemented by scaling the effective damping via the yield force Fwall (Table ??) as cdamping = cbase ·(Fwall/50), producing a 4:1 spread between Delrin and Inconel.
2) Penetration Detection: When the tool enters the workpiece, penetration depth is computed:

xpen = (θcurrent − θwall) · dir ·

π
180
- rh | (7)

where rh = 0.05 m is the effective handle radius.
3) Damping-Based Force Calculation: The cutting force is computed using velocity-proportional damping, scaled by penetration depth:
F = −x˙ filt · cdamping · (1 + dscale) | (8)

where x˙ filt is the filtered velocity at handle (m/s), cdamping =

cbase ×

Fwall
50 is the material-scaled damping with cbase = 2000 Ns/m, and dscale = min xpen
0.005 , 2.0
is the depth scaling factor.
4) Torque-to-PWM Conversion: The computed force is converted to motor torque and then to PWM duty cycle using the Hapkit non-linear mapping:

Tp =

F · rh
gear ratio

(9)

duty =

r
|Tp|
0.03

(10)

This square-root relationship linearizes the perceived force output.

D. Material Properties

Different materials are simulated by varying the wall stiffness kwall and yield force. Table ?? shows the material haptic properties.

TABLE V
MATERIAL HAPTIC PROPERTIES
Material | kwall (N/m) | Yield (N) | Color
Delrin Al 6061 SS316 Inconel | 50,000 100,000 150,000 200,000 | 25 50 75 100 | Cream Silver Steel Bronze

The 4:1 ratio between softest (Delrin) and hardest (Inconel) materials provides clear tactile differentiation.

E. Graphical User Interface

The Processing-based GUI provides: (1) Virtual Lathe Workspace with real-time rendering of stock geometry, tool position, and material removal; (2) Live Readouts of X/Z position, tool load, and cutting parameters; (3) Control Panel for material selection, axis selection, and reset/zero functions; and (4) Connection Status with visual indicator for bridge connectivity.


Fig. 6. Virtual Environment showing the lathe workspace.

1) Collision Detection: The tool uses a hyperbolic profile for realistic V-tool geometry:

y =

p
(s · x)
2 + R² − R | (11)

where s is the slope factor and R is the tool tip radius. Collision is detected when the tool profile intersects the stock profile array at any Z-position.
2) Vibration Frequency Calculation: Cutting vibration frequency is mapped from surface feet per minute (SFM):

SFM =

RPM × D × π
12 | (12)
fvib = SFM [Hz] | (13)

This 1:1 mapping (10 SFM = 10 Hz) provides intuitive correspondence between spindle speed and haptic vibration.

VI. RESULTS

A. Design Decisions
Several key design decisions shaped the final system:
1) Damping-based vs. Spring-based Force Rendering: We chose velocity-proportional damping over pure spring walls because cutting forces in actual machining are primarily determined by feed rate (velocity) rather than static position. This produces a more realistic “cutting feel.”
2) Single-Axis Interface: While a complete lathe has two axes (X and Z), we implemented a single handwheel with software axis selection. This reduces hardware complexity while maintaining training value through the axis toggle feature.
3) Motor as Input and Output: Using the motor encoder as the position input (rather than a separate sensor) enables the same device to serve as both input transducer and force actuator.
B. Limitations
1) Single Degree of Freedom: Real lathe operation involves simultaneous X and Z control. The single-axis interface requires users to mentally switch between axes.
2) No Force Sensing: The system renders forces based on virtual geometry only; actual cutting force measurement would require additional sensors.
3) Motor Backdrive Friction: The geared motor introduces friction that cannot be fully compensated, affecting transparency in free motion.
C. User Study

A formative user study was conducted during a public demonstration of the haptic lathe simulator to evaluate perceived realism, usefulness of the haptic cues, and overall learning impact. The study was exploratory (not a controlled experiment) and focused on subjective perception and qualitative feedback.
1) Procedure: Participants interacted freely with the simulator and were encouraged to (i) toggle between axes, (ii) try multiple materials, and (iii) vary depth of cut and feed behavior to observe changes in resistance and vibration. After the interaction, participants completed a short questionnaire with 10-point Likert items (1 = strongly disagree, 10 = strongly agree) and optional open-ended comments. Participants also answered whether they felt more confident operating a lathe afterward (Yes/No).
2) Participants: Ten participants completed the questionnaire (N = 10). Seven reported prior lathe experience, two reported no prior lathe experience, and one left the question blank. This mix allowed feedback from both experienced users (realism expectations) and novices (interpretability of cues).
3) Measures: Participants rated the following statements:
(1) The simulation was realistic; (2) The materials were differentiable; (3) Force changes communicate tool engagement; (4) I could tell when I was doing something “wrong” based on feel alone; (5) The visual and haptic cues were synchronized; (6) The simulator helped me understand lathe cutting dynamics. Participants also reported whether they felt more confident operating a lathe after use.
4) Results: Table ?? summarizes the Likert responses. Overall scores were high across all dimensions, with particularly strong ratings for visual–haptic synchronization and understanding of cutting dynamics. All participants reported increased confidence operating a lathe after using the simulator (10/10 “Yes”).

TABLE VI
USER STUDY LIKERT RESPONSES (1–10).
Statement | Mean | SD | Range
Simulation was realistic | 8.9 | 0.9 | 8–10
Materials differentiable | 9.0 | 1.1 | 7–10
Force indicates engagement | 9.0 | 1.6 | 6–10
Could detect “wrong” by feel | 8.4 | 1.6 | 5–10
Visual–haptic synchronized | 9.9 | 0.3 | 9–10
Helped understand cutting dynamics | 9.8 | 0.6 | 8–10

TABLE VII
USER STUDY MEANS BY EXPERIENCE GROUP (LIKERT 1–10).
Statement | Experienced (n=7) | Novice (n=2)
Simulation was realistic | 8.6 | 9.5
Materials differentiable | 9.1 | 9.0
Force indicates engagement | 9.1 | 10.0
Could detect “wrong” by feel | 8.1 | 8.5
Visual–haptic synchronized | 9.9 | 9.5
Helped understand cutting dynamics | 9.7 | 10.0

Novice users tended to rate tool engagement and learning impact slightly higher, while experienced users provided more critical realism scores, consistent with expert calibration to real machine feel. Although the novice sample is small, this split suggests the simulator is interpretable for first-time learners while remaining recognizable to users with prior lathe exposure.
5) Qualitative Feedback: Open-ended comments highlighted (i) perceived realism of resistance changes with depth of cut (including experienced-user agreement that it “matched the feel”), and (ii) the usefulness of haptic cues for identifying aggressive cutting without relying on visuals. One participant noted that the suction-cup mounting reduced immersion, suggesting improved fixturing (e.g., clamps or a heavier base) for future iterations.
6) Study Limitations: This evaluation was conducted in an uncontrolled demo setting with a small sample size, so results should be interpreted as formative. Participants had different exposure times and explored different subsets of operations. A controlled follow-on study could standardize tasks (e.g., facing to a target diameter under fixed spindle speed), compare conditions (haptics on/off), and measure objective performance (time-to-completion, overshoot, surface error, and number of “crash” events).
D. Discussion
The results suggest that the simulator successfully conveys key aspects of manual lathe operation through haptic feedback, particularly in communicating tool engagement, material differences, and unsafe cutting conditions. The consistently high ratings for visual–haptic synchronization indicate that the tight coupling between force rendering and graphical feedback contributed to a coherent user experience.
Importantly, both experienced and novice users reported benefits, supporting the hypothesis that physically meaningful handwheel feedback can aid early skill acquisition while remaining recognizable to expert operators. While the small sample size limits statistical generalization, these findings align with prior work emphasizing the role of haptics in motor-skill learning and motivate further controlled studies with larger participant groups.

VII. FUTURE WORK
1) Two-Axis Implementation: Add a second motor/handwheel for simultaneous X and Z control.
2) Force Sensing: Integrate torque sensors for closed-loop force control.
3) Milling Mode: The architecture extends naturally to milling simulation as a stretch goal.
4) Extended User Study: Conduct a formal study comparing training outcomes between haptic and non-haptic simulation.
5) Audio Feedback: Add cutting sounds synchronized with spindle speed and material for multi-modal feedback.

VIII. CONCLUSION
We have presented the design, implementation, and initial evaluation of a haptic lathe training simulator. The system successfully renders material-dependent cutting forces through a directly-driven handwheel interface, enabling users to experience realistic resistance during virtual machining operations. Key contributions include: (1) A three-tier architecture separating visualization, communication, and real-time control; (2) A damping-based force rendering algorithm that produces realistic cutting feel; (3) Material differentiation through adjustable wall stiffness and yield force parameters;
(4) Safety features including crash detection and emergency stop functionality.
The system demonstrates that effective haptic machining training can be achieved with modest hardware (total cost under $60) while providing meaningful tactile feedback for skill development.

ACKNOWLEDGMENTS
AI systems used: Claude Opus 4.5 was used to convert existing codebase documentation and project notes into a well formatted LaTeX final report. The prompt instructed the system to read the repository and the provided background document, produce detailed implementation sections describing the software and hardware (including equations and concept explanations), and insert explicit placeholders wherever required information was missing rather than inventing results. This use primarily improved report structure, formatting quality, and clarity of code and hardware descriptions, while keeping technical content constrained to what was already present in the codebase and project files.
Google Gemini was also selectively used to fix grammatical errors in this report and smooth out sentence structures. The AI was prompted “proof read, dont change tone and content, make list of changes and I will implement them”.

REFERENCES

[1] X. He and Y. Chen, “A Haptic Virtual Turning Operation System,” in Proc. IEEE Int. Conf. on Mechatronics and Automation, Luoyang, China, 2006, pp. 435–440.
[2] S. B. Choudhury, S. K. Saha, and A. K. Mukherjee, “A Virtual Machining Simulator for Training and Education,” IEEE Trans. Learning Technologies, vol. 12, no. 3, pp. 386–398, 2019.
[3] S. Mishra, S. K. Saha, and A. K. Mukherjee, “Development of a virtual machining environment with haptic feedback,” Procedia Manufacturing, vol. 5, pp. 538–549, 2016.
[4] A. D. Silva, J. Pereira, and M. A. Otaduy, “A virtual reality lathe simulator with visuo-haptic feedback for machining training,” Virtual Reality, vol. 27, no. 2, pp. 1121–1136, 2023.
[5] C. Basdogan, S. De, J. Kim, M. Muniyandi, H. Kim, and M. A. Srinivasan, “Haptics in minimally invasive surgical simulation and training,” IEEE Computer Graphics and Applications, vol. 24, no. 2, pp. 56–64, 2004.
[6] K. Salisbury, F. Conti, and F. Barbagli, “Haptic rendering: introductory concepts,” IEEE Computer Graphics and Applications, vol. 24, no. 2, pp. 24–32, 2004.
[7] A. Akshay, R. Raghavan, and S. K. Saha, “Significance of Haptic Feedback in Learning Lathe Operating Skills,” in Proc. IEEE Tenth Int. Conf. on Technology for Education (T4E), Chennai, India, 2018, pp. 112–119.
[8] J. K. Salisbury, K. J. Kuchenbecker, and the Stanford Haptics Group, “The Hapkit: A low-cost haptic device for education and research,” Stanford University. [Online]. Available: https://hapkit.stanford.edu
[9] Turnin’ and Burnin’ Haptic Lathe Project, Lafayette College. [Online]. Available: https://sites.lafayette.edu/turnin-and-burnin/

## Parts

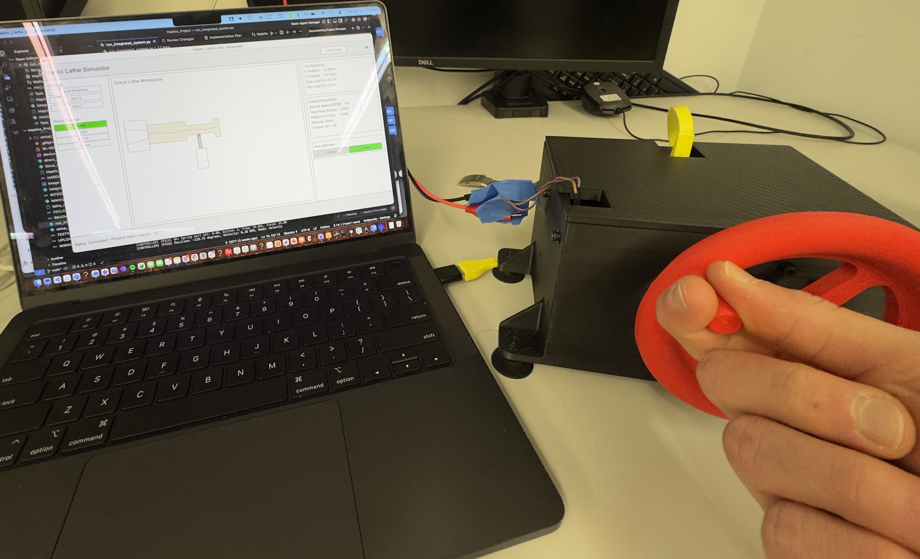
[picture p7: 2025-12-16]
Report Materials/lathe_demo.jpg

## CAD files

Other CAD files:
New+Assembly.f3z

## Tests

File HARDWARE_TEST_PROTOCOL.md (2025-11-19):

# 🔬 Hardware Testing Protocol for CQR37D Haptic Lathe System

## ⚠️ **CURRENT STATUS: CODE COMPLETE, HARDWARE TESTING REQUIRED**

### **What We've Built (Software)**
✅ Complete integrated lathe GUI with motor controls
✅ File-based communication between GUI and controller
✅ Motor control algorithms (position, velocity, safety)
✅ Encoder reading and position tracking
✅ Safety systems and emergency stop
✅ Simulated testing (fake sine wave data)

### **What Needs Real Hardware Testing**
❌ Actual encoder position reading from CQR37D motor
❌ Actual motor movement commands
❌ Physical handle wheel ↔ motor shaft connection
❌ Real-time position feedback accuracy
❌ Motor safety limits and error handling

---

## 🧪 **Step-by-Step Hardware Testing Protocol**

### **Phase 1: Basic Hardware Setup**

#### **1.1 Upload Motor Control to Pico**
```bash
# Connect Pico to computer (hold BOOTSEL button)
# Copy motor_control.py to Pico using Thonny IDE
```

#### **1.2 Hardware Connections**
```
CQR37D Motor → DROK XY-160D Controller → Raspberry Pi Pico

Motor Pins:
- Red: + Power (6-24V DC)
- Black: - Power (GND)

Controller → Pico:
- ENA (PWM): GP0 (Pin 1)
- IN1 (DIR): GP1 (Pin 2)

Encoder → Pico:
- A (White): GP8 (Pin 9)
- B (Yellow): GP9 (Pin 10)
- + (Red): 3.3V
- - (Black): GND
```

#### **1.3 Power Supply**
- **Motor Power**: 12V DC recommended (check motor specs)
- **Pico Power**: USB 5V
- **Controller Logic**: 3.3V-5V compatible

---

### **Phase 2: Basic Motor Testing**

#### **2.1 Test Encoder Reading**
```python
# On Pico, run:
from test_motor import test_encoder
test_encoder()
# Manually rotate motor shaft
# Should show encoder count changes
```

**Expected Results:**
- Encoder counts increase/decrease when rotating
- Noisy counts = wiring issue
- No counts = encoder not connected

#### **2.2 Test Motor Movement**
```python
# On Pico, run:
from test_motor import test_motor_directions
test_motor_directions()
# Motor should move CW then CCW
```

**Expected Results:**
- Smooth motor rotation in both directions
- Position changes match expected RPM
- No stuttering = PWM working correctly

#### **2.3 Test Position Control**
```python
# On Pico, run motor_control.py directly
pos 180  # Move to 180 degrees
status   # Check position
pos 0    # Return to zero
```

**Expected Results:**
- Motor moves to exact position
- Holds position against manual force
- Smooth movement, no oscillations

---

### **Phase 3: Integrated System Testing**

#### **3.1 Start Python Controller**
```bash
python3 integrated_lathe_controller.py
# Should show: "Connected to Pico on /dev/ttyACM1"
```

#### **3.2 Start Processing GUI**
```bash
# Open Haptic_Lathe_GUI_Integrated.pde in Processing IDE
# Click Run
```

**Expected Results:**
- GUI shows green connection dot
- Footer shows "Connected • Handle: X.X°"
- Motor control buttons visible

#### **3.3 Test Motor Control Buttons**
1. Click **Forward** button → Motor moves CW
2. Click **Reverse** button → Motor moves CCW
3. Click **Stop** button → Motor stops
4. Try **±1°** / **±10°** position buttons
5. Select different speeds (Slow/Medium/Fast)

**Expected Results:**
- Motor responds immediately to button clicks
- Speed changes work correctly
- Position buttons move motor by exact amounts
- Encoder position updates in real-time in GUI

#### **3.4 Test Handle Wheel Integration**
1. Physically attach handle wheel to motor shaft
2. Turn handle wheel manually
3. Observe GUI position updates
4. Test "Physical Input" mode toggle

**Expected Results:**
- Handle wheel rotation = GUI tool movement
- Smooth, accurate position tracking
- No lag or jitter in position display

---

### **Phase 4: Safety and Performance Testing**

#### **4.1 Emergency Stop Testing**
- Press **Spacebar** during motor movement
- Motor should stop immediately
- GUI should show emergency state

#### **4.2 Error Handling**
- Disconnect encoder wires during operation
- System should detect and stop safely
- GUI should show error state

#### **4.3 Performance Testing**
- High-speed motor movement
- Rapid position changes
- Continuous operation for 10+ minutes
- Temperature monitoring

---

## 📊 **Testing Results Template**

### **Test Session Date:** __________

#### **Hardware Configuration:**
- Pico firmware version: __________
- Motor voltage: __________ V
- Gear ratio: __________ :1
- Encoder CPR: __________ counts

#### **Phase 1 Results:**
- [ ] Pico programming successful
- [ ] All connections secure
- [ ] Power supplies stable

#### **Phase 2 Results:**
- [ ] Encoder reading: __________ counts/change
- [ ] Motor CW movement: __________ °/5sec
- [ ] Motor CCW movement: __________ °/5sec
- [ ] Position control accuracy: __________ °

#### **Phase 3 Results:**
- [ ] GUI connection: [ ] Stable [ ] Intermittent [ ] Failed
- [ ] Motor buttons: [ ] Working [ ] Sluggish [ ] Failed
- [ ] Position updates: [ ] Real-time [ ] Delayed [ ] Failed
- [ ] Handle wheel: [ ] Accurate [ ] Jittery [ ] Failed

#### **Phase 4 Results:**
- [ ] Emergency stop: [ ] Instant [ ] Delayed [ ] Failed
- [ ] Error handling: [ ] Safe [ ] Unsafe [ ] Failed
- [ ] Performance: [ ] Good [ ] Issues [ ] Failed

### **Issues Found:**
1. _______________________________
2. _______________________________
3. _______________________________

### **Overall Assessment:**
[ ] **PASS** - System ready for use
[ ] **CONDITIONAL PASS** - Minor issues, usable
[ ] **FAIL** - Major issues require fixes

---

## 🛠️ **Troubleshooting Guide**

### **GUI Shows "Disconnected"**
1. Check Python controller is running
2. Verify `/tmp/lathe_bridge_status.json` exists
3. Check file permissions

### **Motor Not Moving**
1. Verify power supply voltage
2. Check PWM and DIR pin connections
3. Test with direct motor_control.py commands

### **Encoder Not Reading**
1. Check encoder A/B wire colors
2. Verify 3.3V power to encoder
3. Test encoder continuity

### **Position Inaccurate**
1. Verify gear ratio setting
2. Check encoder CPR value
3. Calibrate zero position

---

## 🎯 **Success Criteria**

### **Minimum Viable System:**
- ✅ GUI connects and shows motor controls
- ✅ Motor moves in response to GUI buttons
- ✅ Encoder position updates in GUI
- ✅ Emergency stop works

### **Full System Success:**
- ✅ All above + handle wheel integration
- ✅ Smooth, accurate position control
- ✅ Safety systems functional
- ✅ Reliable operation for extended periods

---

## 📞 **Ready for Physical Testing**

**The software is complete and ready for real hardware testing.** Connect your CQR37D motor, Pico, and controller, then follow this protocol to verify everything works end-to-end.

**Only after successful hardware testing can we claim the system is fully functional!** 🔬⚙️

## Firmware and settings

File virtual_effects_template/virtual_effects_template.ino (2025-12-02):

//--------------------------------------------------------------------------
// Code to test basic Hapkit functionality (sensing and force output)
// Contributors to code: Allison Okamura, Tania Morimoto, Melisa Orta Martinez
// Updated by Cara Nunez 9.19.2024
//--------------------------------------------------------------------------
// Parameters that define what environment to render
#define ENABLE_VIRTUAL_WALL
//#define ENABLE_LINEAR_DAMPING
//#define ENABLE_NONLINEAR_FRICTION
//#define ENABLE_HARD_SURFACE
//#define ENABLE_BUMP_VALLEY
//#define ENABLE_TEXTURE

// Includes
#include <math.h>

// Pin declares
int pwmPin = 5; // PWM output pin for motor 1
int dirPin = 8; // direction output pin for motor 1
int sensorPosPin = A2; // input pin for MR sensor
int fsrPin = A3; // input pin for FSR sensor

// Position tracking variables
int updatedPos = 0;     // keeps track of the latest updated value of the MR sensor reading
int rawPos = 0;         // current raw reading from MR sensor
int lastRawPos = 0;     // last raw reading from MR sensor
int lastLastRawPos = 0; // last last raw reading from MR sensor
int flipNumber = 0;     // keeps track of the number of flips over the 180deg mark
int tempOffset = 0;
int rawDiff = 0;
int lastRawDiff = 0;
int rawOffset = 0;
int lastRawOffset = 0;
const int flipThresh = 700;  // threshold to determine whether or not a flip over the 180 degree mark occurred
boolean flipped = false;

// Kinematics variables
double xh = 0;           // position of the handle [m]
double theta_s = 0;      // Angle of the sector pulley in deg
double xh_prev;          // Distance of the handle at previous time step
double xh_prev2;
double dxh;              // Velocity of the handle
double dxh_prev;
double dxh_prev2;
double dxh_filt;         // Filtered velocity of the handle
double dxh_filt_prev;
double dxh_filt_prev2;

// Force output variables
double force = 0;           // force at the handle
double Tp = 0;              // torque of the motor pulley
double duty = 0;            // duty cylce (between 0 and 255)
unsigned int output = 0;    // output command to the motor


// --------------------------------------------------------------
// Setup function -- NO NEED TO EDIT
// --------------------------------------------------------------
void setup() 
{
  // Set up serial communication
  Serial.begin(9600);
  
  // Set PWM frequency 
  setPwmFrequency(pwmPin,1); 
  
  // Input pins
  pinMode(sensorPosPin, INPUT); // set MR sensor pin to be an input
  pinMode(fsrPin, INPUT);       // set FSR sensor pin to be an input

  // Output pins
  pinMode(pwmPin, OUTPUT);  // PWM pin for motor A
  pinMode(dirPin, OUTPUT);  // dir pin for motor A
  
  // Initialize motor 
  analogWrite(pwmPin, 0);     // set to not be spinning (0/255)
  digitalWrite(dirPin, LOW);  // set direction
  
  // Initialize position valiables
  lastLastRawPos = analogRead(sensorPosPin);
  lastRawPos = analogRead(sensorPosPin);
}


// --------------------------------------------------------------
// Main Loop
// --------------------------------------------------------------
void loop()
{
  
  //*************************************************************
  //*** Section 1. Compute position in counts (do not change) ***  
  //*************************************************************

  // Get voltage output by MR sensor
  rawPos = analogRead(sensorPosPin);  //current raw position from MR sensor

  // Calculate differences between subsequent MR sensor readings
  rawDiff = rawPos - lastRawPos;          //difference btwn current raw position and last raw position
  lastRawDiff = rawPos - lastLastRawPos;  //difference btwn current raw position and last last raw position
  rawOffset = abs(rawDiff);
  lastRawOffset = abs(lastRawDiff);
  
  // Update position record-keeping vairables
  lastLastRawPos = lastRawPos;
  lastRawPos = rawPos;
  
  // Keep track of flips over 180 degrees
  if((lastRawOffset > flipThresh) && (!flipped)) { // enter this anytime the last offset is greater than the flip threshold AND it has not just flipped
    if(lastRawDiff > 0) {        // check to see which direction the drive wheel was turning
      flipNumber--;              // cw rotation 
    } else {                     // if(rawDiff < 0)
      flipNumber++;              // ccw rotation
    }
    if(rawOffset > flipThresh) { // check to see if the data was good and the most current offset is above the threshold
      updatedPos = rawPos + flipNumber*rawOffset; // update the pos value to account for flips over 180deg using the most current offset 
      tempOffset = rawOffset;
    } else {                     // in this case there was a blip in the data and we want to use lastactualOffset instead
      updatedPos = rawPos + flipNumber*lastRawOffset;  // update the pos value to account for any flips over 180deg using the LAST offset
      tempOffset = lastRawOffset;
    }
    flipped = true;            // set boolean so that the next time through the loop won't trigger a flip
  } else {                        // anytime no flip has occurred
    updatedPos = rawPos + flipNumber*tempOffset; // need to update pos based on what most recent offset is 
    flipped = false;
  }
 
  //*************************************************************
  //*** Section 2. Compute position in meters *******************
  //*************************************************************

  // ADD YOUR CODE HERE (Use your code from Problems 1 and 2)
  // ADD YOUR CODE HERE (Use ypur code from Problems 1 and 2)
  // Define kinematic parameters you may need
double rh = 0.069;   //[m]
  // Step B.1: print updatedPos via serial monitor
 double ts =updatedPos*0.0125-2.2; // Compute the angle of the sector pulley (ts) in degrees based on updatedPos
  double tsrad=ts*(3.14/180);
  //sin(tsrad)=xh/rh
  xh=sin(tsrad)*rh;
  //Serial.println(xh,5);
  //xhmax=0.04798
  //xhmin=-0.05809
  // Step B.7: xh = ?;       // Compute the position of the handle (in meters) based on ts (in radians)
  // Step B.8: print xh via serial monitor

  // Calculate velocity with loop time estimation
  dxh = (double)(xh - xh_prev) / 0.001;

  // Calculate the filtered velocity of the handle using an infinite impulse response filter
  dxh_filt = .9*dxh + 0.1*dxh_prev; 
    
  // Record the position and velocity
  xh_prev2 = xh_prev;
  xh_prev = xh;
  
  dxh_prev2 = dxh_prev;
  dxh_prev = dxh;
  
  dxh_filt_prev2 = dxh_filt_prev;
  dxh_filt_prev = dxh_filt;
  
  //*************************************************************
  //*** Section 3. Assign a motor output force in Newtons *******  
  //*************************************************************
  //*************************************************************
  //******************* Rendering Algorithms ********************
  //*************************************************************
   
 
  
  //*************************************************************
  //*** Section 3. Assign a motor output force in Newtons *******  
  //*************************************************************
 
  // ADD YOUR CODE HERE
  // Define kinematic parameters you may need
     //double rp = 0.0092;   //[m]
     //double rs = 0.075;   //[m] 
     //double rhandle = 0.089;   //[m] 
  //force = 0; // You can  generate a force by assigning this to a constant number (in Newtons) or use a haptic rendering / virtual environment
// double k=5;
// double force=-k*xh;
// Tp = force*0.01092;    


// Pick which effect is active
#define EFFECT_VIRTUAL_WALL  (1)
#define EFFECT_SPRING        (2)
#define EFFECT_DAMPER        (3)
#define EFFECT_KARNOPP       (4)
#define EFFECT_HARD_SURFACE  (5)
#define EFFECT_BUMPNVALLEY   (6)
#define EFFECT_TEXTURED      (7)


//ACTIVE_EFFECT=EFFECT_VIRTUAL_WALL

#define ACTIVE_EFFECT EFFECT_VIRTUAL_WALL 

#if ACTIVE_EFFECT==EFFECT_VIRTUAL_WALL
if (xh > 0.005) {
  double k = 200.0;
   force = -k * (xh - 0.005);
  Tp = force * 0.01092;   // motor pulley torque
}
else {
    Tp = 0.0;
  }
#endif

//Serial.println(xh,1);



#if ACTIVE_EFFECT==EFFECT_DAMPER
double cdamping=5.0; //N*s/m
   force=-dxh_filt*cdamping;
  Tp = force * 0.01092;   // motor pulley torque

#endif

#if ACTIVE_EFFECT == EFFECT_KARNOPP


static int   sign_hold = 0;     // -1, 0, +1 (held friction sign near zero)
static int   in_rest   = 1;     // 1 = rest (stick), 0 = slip
static double x_hold   = 0.0;   // rest (anchor) position for the stiff spring

double Fc    = 0.5;             // Coulomb [N]
double B     = 0.2;             // viscous [N*s/m]
double v_on  = 0.1;           // leave-rest threshold [m/s]
double v_off = 0.01;           // enter-rest threshold [m/s]

double F_s   = 20.0;             // static limit [N] (>= Fc)
double k_static = 700.0;        // very stiff spring [N/m] active only at rest

double v = dxh_filt;

//  Update hysteresis sign based on velocity 
if (v >  v_on)  sign_hold = +1;
else if (v < -v_on) sign_hold = -1;
else if (fabs(v) < v_off) sign_hold = 0;


//  State transitions 
if (fabs(v) > v_on) {
  in_rest = 0;  // moving fast enough → slip
} else if (fabs(v) < v_off && in_rest == 0) {
  // just re-entered rest: latch a new anchor
  x_hold = xh_prev;
  in_rest = 1;
}
 //Serial.println(v, 3);

if (in_rest) {
  // Stiff virtual spring around x_hold
  double F_spring = -k_static * (xh - x_hold);

  // Clamp spring to static limit
  if (F_spring >  F_s) F_spring =  F_s;
  if (F_spring < -F_s) F_spring = -F_s;

  // If the spring hits the static limit, we are at breakaway 
  if (fabs(F_spring) >= F_s && fabs(v) >= v_off) {
    in_rest = 0;  // breakaway
   // Serial.println("Breakaway");
  }
  force = F_spring;                 // oppose small forces at rest
  //Serial.println(F_spring, 3);
} else {
  // Slip: viscous + Coulomb opposing motion 
  int s = sign_hold;
  if (s == 0) s = (v > 0) ? 1 : -1;
  force = -(B * v) - Fc * s;
}

Tp = force * 0.01092;
#endif



#if ACTIVE_EFFECT == EFFECT_HARD_SURFACE
 double v = dxh_filt;
 double impact=v*10.0;
 double k = 100.0;
 double spring_force=0;
 int t=0;
 if ((xh > 0.005) && (v>0.005)){
    for (int t=1; t<=10; ++t){
      spring_force = -k * (xh - 0.005);
        force = spring_force + (impact * sin((double)t) * exp(-0.1 * (double)t));
        Tp = force * 0.01092;   // motor pulley torque
    } 
  }
else if  (xh > 0.005) {
   spring_force = -k * (xh - 0.005);
  Tp = spring_force * 0.01092;   // motor pulley torque
}

else {
    Tp = 0.0;
  }
#endif



#if ACTIVE_EFFECT == EFFECT_BUMPNVALLEY
 int t=0;
 double hill_xs=0.02;
double hill_xe=0.04;
double valley_xs=-0.02;
  double valley_xe=-0.03;

 if (xh > hill_xs && xh<hill_xe) 
 {
        force =  3*sin((xh - hill_xs)*3.1415/(hill_xe-hill_xs));
        //  Serial.println(force,5);

        Tp = force * 0.01092;   // motor pulley torque
    } 
  
else if (xh < valley_xs && xh>valley_xe) 
{
       force =  3*sin(((xh - valley_xs)*3.1415)/(valley_xs-valley_xe));
       Tp = force * 0.01092;   // motor pulley torque
      // Serial.println(force,5);
   } 
  
else {
    Tp = 0.0;
  }
#endif



#if ACTIVE_EFFECT ==EFFECT_TEXTURED
 double v = dxh_filt;
 double impact=v*10.0;
 int t=0;
 if (v>0.005){
    for (int t=1; t<=10; ++t){
        force = (impact * sin((double)t) * exp(-0.1 * (double)t));
        Tp = force * 0.01092;   // motor pulley torque
    } 
  }

else {
    Tp = 0.0;
  }
#endif


  //*************************************************************
  //*** Section 4. Force output (do not change) *****************
  //*************************************************************
  
  // Determine correct direction for motor torque
  if(force > 0) { 
    digitalWrite(dirPin, HIGH);
  } else {
    digitalWrite(dirPin, LOW);
  }

  // Compute the duty cycle required to generate Tp (torque at the motor pulley)
  duty = sqrt(abs(Tp)/0.03);

  // Make sure the duty cycle is between 0 and 100%
  if (duty > 1) {            
    duty = 1;
  } else if (duty < 0) { 
    duty = 0;
  }  
  output = (int)(duty* 255);   // convert duty cycle to output signal
  analogWrite(pwmPin,output);  // output the signal
}

// --------------------------------------------------------------
// Function to set PWM Freq -- DO NOT EDIT
// --------------------------------------------------------------
void setPwmFrequency(int pin, int divisor) {
  byte mode;
  if(pin == 5 || pin == 6 || pin == 9 || pin == 10) {
    switch(divisor) {
      case 1: mode = 0x01; break;
      case 8: mode = 0x02; break;
      case 64: mode = 0x03; break;
      case 256: mode = 0x04; break;
      case 1024: mode = 0x05; break;
      default: return;
    }
    if(pin == 5 || pin == 6) {
      TCCR0B = TCCR0B & 0b11111000 | mode;
    } else {
      TCCR1B = TCCR1B & 0b11111000 | mode;
    }
  } else if(pin == 3 || pin == 11) {
    switch(divisor) {
      case 1: mode = 0x01; break;
      case 8: mode = 0x02; break;
      case 32: mode = 0x03; break;
      case 64: mode = 0x04; break;
      case 128: mode = 0x05; break;
      case 256: mode = 0x06; break;
      case 1024: mode = 0x7; break;
      default: return;
    }
    TCCR2B = TCCR2B & 0b11111000 | mode;
  }
}

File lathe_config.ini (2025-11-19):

# Integrated Haptic Lathe System Configuration
# Edit these values based on your setup

[serial_ports]
# Serial port for GUI communication (leave empty for auto-detection)
gui_port =

# Serial port for Pico motor controller (leave empty for auto-detection)
pico_port =

[motor_config]
# Motor encoder counts per revolution (fixed for CQR37D)
encoder_cpr = 64

# Gear ratio of your motor
gear_ratio = 30.0

# Maximum RPM for your motor/voltage combination
max_rpm = 150.0

[safety_limits]
# Maximum velocity (RPM)
max_velocity = 100.0

# Maximum position error before safety stop (degrees)
max_position_error = 10.0

# Heartbeat timeout (seconds)
heartbeat_timeout = 5.0

[gui_config]
# GUI update rate (Hz)
update_rate = 10

# Enable physical input by default
physical_input_default = true

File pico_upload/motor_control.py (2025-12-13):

"""
Raspberry Pi Pico Motor Control for CQR37D Geared Motor
Controls angular position and velocity through command line interface

Hardware Connections:
- Encoder A (white): GP8 (Pico pin 9)
- Encoder B (yellow): GP9 (Pico pin 10)
- Motor ENA: GP0 (Pico pin 1) - PWM for speed
- Motor IN1: GP1 (Pico pin 2) - Direction control

CQR37D Specifications:
- 64 counts per revolution (CPR) quadrature encoder
- Gear ratios available: 6.25:1 to 810:1 (assuming 30:1 for this example)
"""

import machine
import time
import math
from machine import Pin, PWM
import select
import sys

# Motor and Encoder Configuration
class MotorController:
    def __init__(self):
        # Encoder pins (interrupt capable)
        self.encoder_a = Pin(6, Pin.IN, Pin.PULL_UP)  # GP6, Pico pin 9 (white wire)
        self.encoder_b = Pin(7, Pin.IN, Pin.PULL_UP)  # GP7, Pico pin 10 (yellow wire)

        # Motor control pins for dual H-bridge controller
        self.motor_ena_pin = Pin(0)  # GP0 raw pin reference
        self.motor_ena = PWM(self.motor_ena_pin)  # GP0, Pico pin 1 - PWM for speed (ENA)
        self.motor_ena_enabled = True  # Track if PWM is active
        self.motor_in1 = Pin(2, Pin.OUT)  # GP2, Pico pin 4 - Direction control (IN1)
        self.motor_in2 = Pin(1, Pin.OUT)  # GP1, Pico pin 2 - Direction control (IN2)

        # Encoder configuration
        self.CPR = 64  # Counts per revolution (motor shaft)
        self.gear_ratio = 30.0  # Example gear ratio (adjust based on your motor)
        self.counts_per_output_rev = self.CPR * self.gear_ratio

        # Position tracking
        self.encoder_count = 0
        self.last_a_state = self.encoder_a.value()
        self.last_b_state = self.encoder_b.value()

        # Velocity tracking
        self.last_time = time.ticks_us()
        self.last_count = 0
        self.current_velocity = 0.0  # RPM

        # Control variables
        self.target_position = 0.0  # degrees
        self.target_velocity = 0.0  # RPM
        self.current_position = 0.0  # degrees
        self.control_mode = "velocity"  # "position" or "velocity"
        self.last_motion_sign = 0  # Tracks last observed rotation direction

        # PID parameters for position control
        self.kp = 2.0
        self.ki = 0.1
        self.kd = 0.05
        self.integral_error = 0.0
        self.last_position_error = 0.0

        # Virtual wall (encoder-backed hold) state
        self.wall_engaged = False
        self.wall_contact_position_deg = 0.0
        self.wall_direction = 1  # +1/-1 penetration direction
        self.wall_force_newtons = 0.0
        self.wall_kp_min = 1.0
        self.wall_kp_max = 8.0
        self.wall_kd_min = 0.02
        self.wall_kd_max = 0.12
        self.wall_release_tol_deg = 0.25  # deadband around wall surface
        self.last_wall_error = 0.0
        self.last_wall_time_ms = time.ticks_ms()
        self.prev_position_deg = 0.0

        # Haptic feedback
        self.haptic_brake_percent = 0.0  # 0.0 to 1.0 (0% to 100% braking)
        self.vib_freq = 10.0  # Default vibration frequency [Hz]
        self.yield_force = 50.0  # Force at which wall yields (cuts) [N]

        # PWM configuration
        self.motor_ena.freq(1000)  # 1kHz PWM frequency
        self.max_pwm = 65535
        self.min_pwm = 1000  # Minimum PWM to overcome motor deadband
        # Limit the braking duty cycle to avoid overheating while keeping it proportional
        self.max_brake_scale = 0.6

        # Setup encoder interrupts
        self.encoder_a.irq(trigger=Pin.IRQ_RISING | Pin.IRQ_FALLING, handler=self.encoder_callback)
        self.encoder_b.irq(trigger=Pin.IRQ_RISING | Pin.IRQ_FALLING, handler=self.encoder_callback)

        print("Motor controller initialized")
        print(f"Encoder CPR: {self.CPR}, Gear ratio: {self.gear_ratio}")
        print(f"Counts per output revolution: {self.counts_per_output_rev}")

    def encoder_callback(self, pin):
        """Interrupt handler for encoder signals"""
        a_state = self.encoder_a.value()
        b_state = self.encoder_b.value()

        # Quadrature decoding
        if a_state != self.last_a_state:
            if a_state == b_state:
                self.encoder_count += 1
            else:
                self.encoder_count -= 1

        self.last_a_state = a_state
        self.last_b_state = b_state

    def get_position_degrees(self):
        """Get current position in degrees"""
        revolutions = self.encoder_count / self.counts_per_output_rev
        return revolutions * 360.0

    def get_velocity_rpm(self):
        """Calculate current velocity in RPM"""
        current_time = time.ticks_us()
        current_count = self.encoder_count

        dt = time.ticks_diff(current_time, self.last_time) / 1000000.0  # seconds
        if dt > 0.01:  # Update every 10ms minimum
            count_diff = current_count - self.last_count
            rev_per_sec = count_diff / self.counts_per_output_rev
            self.current_velocity = rev_per_sec * 60.0
            if count_diff > 0:
                self.last_motion_sign = 1
            elif count_diff < 0:
                self.last_motion_sign = -1

            self.last_time = current_time
            self.last_count = current_count

        return self.current_velocity

    def set_motor_speed(self, speed_rpm):
        """Set motor speed in RPM (positive = one direction, negative = other)"""
        # Update target velocity tracker so haptic logic knows the current command
        self.target_velocity = speed_rpm

        # If haptics are active, braking takes priority over driving to create resistance
        if self._apply_haptic_brake():
            return

        if abs(speed_rpm) < 0.1:  # Stop threshold
            self.motor_disable()  # True free spin
            # Set both IN pins HIGH for symmetric coast
            self.motor_in1.value(1)
            self.motor_in2.value(1)
            self.last_motion_sign = 0
            return

        # Direction control for dual H-bridge
        # Forward: IN1=HIGH, IN2=LOW
        # Reverse: IN1=LOW, IN2=HIGH
        if speed_rpm > 0:
            self.motor_in1.value(1)
            self.motor_in2.value(0)
            self.last_motion_sign = 1
        else:
            self.motor_in1.value(0)
            self.motor_in2.value(1)
            self.last_motion_sign = -1

        # Speed (scale RPM to PWM duty cycle)
        # Assuming max RPM is around 100-200 for geared motor, adjust as needed
        max_rpm = 150.0
        duty_percent = min(abs(speed_rpm) / max_rpm, 1.0)

        duty_value = int(self.min_pwm + (self.max_pwm - self.min_pwm) * duty_percent)
        self.motor_enable()  # Ensure PWM mode is active
        self.motor_ena.duty_u16(duty_value)

    def _apply_haptic_brake(self):
        """Apply electromagnetic braking using Hapkit-style torque control.
        Based on Arduino Hapkit algorithm for proper force rendering.
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

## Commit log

2025-11-18 Add Raspberry Pi Pico motor control code for CQR37D motor
    - motor_control.py: Complete MicroPython script for position and velocity control
    - README.md: Comprehensive documentation and setup instructions
    - Supports quadrature encoder with 64 CPR
    - Command-line interface for motor control
    - PID-based position control and direct velocity control
2025-11-18 Add motor testing and calibration utilities
    - test_motor.py: Comprehensive test suite for motor and encoder functionality
    - calibrate_motor.py: Interactive calibration tools for gear ratio, max speed, and PID tuning
    - Both scripts work with the existing motor_control.py framework
2025-11-18 Add comprehensive testing guide and quick reference
    - TESTING_GUIDE.md: Step-by-step testing procedures and troubleshooting
    - quick_test.py: Simple test commands for REPL testing
    - Covers encoder, motor, velocity, and position control testing
    - Includes calibration procedures and safety guidelines
2025-11-18 Complete motor control system with upload automation
    - upload_and_test.py: Automated upload and testing workflow script
    - pico_upload/: Organized directory with all Pico files ready for upload
    - Complete testing and calibration framework
    - Step-by-step instructions for hardware setup and testing
    - Emergency stop procedures and troubleshooting guides
2025-11-19 Add X/Z axis switching and haptic feedback
    - Added axis selector buttons (X/Z) in GUI motor control panel
    - Motor movement now maps to selected axis (X=radial, Z=axial)
    - Implemented collision detection between tool tip and stock
    - Added haptic feedback system with motor braking on collision
    - Visual feedback: red circle when tool collides with stock
    - Motor applies resistance proportional to collision force
    [Haptic_Lathe_GUI_Integrated.pde, integrated_lathe_controller.py, lathe_config.ini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]
2025-11-19 Cleanup: Remove test files, debug scripts, and temporary files
    - Removed 40+ test/debug scripts (*_test.py, debug_*.py, etc.)
    - Removed cache files (__pycache__, .DS_Store)
    - Removed binary files (micropython.uf2)
    - Removed duplicate/old files
    - Added .gitignore to prevent re-adding temporary files
    - Kept essential files: main bridge, Pico firmware, GUI, documentation
    [Haptic_Lathe_GUI_Integrated.pde, motor_control.py]
2025-12-02 Fix haptic feedback: Correct physics implementation
    - Tool now starts OUTSIDE workpiece (air cutting position)
    - Air cutting (outside stock): force=0 = Easy to turn
    - Light contact: force=20-40 = Moderate resistance
    - Deep cutting: force=80-100 = Maximum resistance
    - Added passive electromagnetic braking when motor is idle
    - Collision detection now sends correct force values
    - Tool positioned 20px outside stock radius at startup
    [Haptic_Lathe_GUI_Integrated.pde, motor_control.py]
2025-12-03 Fix V-tool geometry, reduce vibration, increase stiffness, add spacebar toggle
    [Haptic_Lathe_GUI_Integrated.pde, direct_upload.py, motor_control.py]
2025-12-04 Fix radial feedback direction, half-profile cutting, and material addition glitch
    [Haptic_Lathe_GUI_Integrated.pde, integrated_lathe_controller.py]
2025-12-04 Fix persistent vibration, implement symmetric cutting, and correct force feedback logic
    [Haptic_Lathe_GUI_Integrated.pde, direct_upload.py, motor_control.py]
2025-12-04 Implement dynamic vibration (SFM-based frequency, Force-based amplitude) and fix feedback loop
    [Haptic_Lathe_GUI_Integrated.pde, integrated_lathe_controller.py, motor_control.py]
2025-12-04 Fix Reset Workpiece button in GUI - add stockProfile and initStockProfile
    [Haptic_Lathe_GUI_Improved_graphics.pde]
2025-12-04 Add stock bounds check and 100x damping when spindle off
2025-12-04 GUI refactoring and haptic feedback improvements - buttons work on click, reset moves tool, no feedback past stock
    [Haptic_Lathe_GUI_Integrated.pde]
2025-12-04 Add crash detection for spindle-off collisions, wave centerline animation, parting-off feature
    [Haptic_Lathe_GUI_Integrated.pde, motor_control.py]
2025-12-04 Reverse direction of travel for X and Z axes, update force reaction directions
    [Haptic_Lathe_GUI_Integrated.pde]
2025-12-13 feat: Add material selection with differentiated haptic feedback
    - Add material selection (Delrin, Al 6061, SS316) with distinct k_wall values
    - Add material-specific yield forces (25N, 50N, 75N)
    - Fix radial penetration to use area-based calculation matching axial
    - Increase base damping coefficient (500 -> 2000) for more noticeable feel
    - Scale Pico damping by GUI force value for material differentiation
    - Increase force cap from 50N to 100N
    - Remove 5x radial multiplier for consistent radial/axial feel
    - Update bridge to parse and forward yield values to Pico
    [Haptic_Lathe_GUI_Integrated.pde, integrated_lathe_controller.py, motor_control.py]
2025-12-13 fix: Motor free spin with symmetric coast mode
    - Add motor_disable() to drive ENA LOW as GPIO for true free spin
    - Add motor_enable() to re-init PWM mode when motor control needed
    - Set IN1=IN2=HIGH when disabling for symmetric coast
    - Increase area-based force scaling from 30x to 45x (1.5x boost)
    - Fix radial penetration to use area-based formula matching axial
    [lathe_config.ini, motor_control.py]
2025-12-13 feat: Add Inconel material (2x Al 6061), arrow keys for spindle
    - Add Inconel material with 200000 N/m stiffness (2x Al 6061)
    - Up/Down arrow keys control spindle speed (50 RPM increments)
    - Comment out all println debug statements
    - Restore motor_control.py with symmetric coast mode
    [Haptic_Lathe_GUI_Integrated.pde]
2025-12-13 fix: Reduce parting-off threshold to 2px to prevent premature cut-through
    [Haptic_Lathe_GUI_Integrated.pde]
2025-12-13 refactor: Clean up AI-generated code slop
    - Remove duplicate force clamp line in motor_control.py
    - Remove verbose inline comments throughout codebase
    - Remove empty debug frame blocks with commented-out prints
    - Simplify conditionals and remove unnecessary nesting
    [Haptic_Lathe_GUI_Integrated.pde, motor_control.py]
2025-12-13 docs: Add Report Materials
2025-12-16 docs: Reformat final report to IEEE conference format
    - Convert document class from article to IEEEtran conference
    - Add IEEE author block formatting
    - Add IEEE keywords section
    - Convert tables to IEEE style with borders
    - Update figure sizing for two-column layout
    - Add TikZ system architecture diagram
    - Include device.png and image.png figures
    - Remove table of contents (not standard for conference papers)
    - Fix bibliography formatting
2025-12-16 docs: Add tables to improve report readability
    - Add System Update Rates table (Table I)
    - Add CQR37D Motor Specifications table (Table II)
    - Add Bill of Materials table (Table IV)
    - Add User Study Results table (Table VIII)
2025-12-16 Move report images to Report Materials folder
    - Moved image2.png and image3.png from root to Report Materials/
    - Removed duplicate image.png and device.png from root
    - All images referenced in final_report.tex are now in Report Materials/
2025-12-16 Add CAD assembly file and update file descriptions in report
    [New+Assembly.f3z]
